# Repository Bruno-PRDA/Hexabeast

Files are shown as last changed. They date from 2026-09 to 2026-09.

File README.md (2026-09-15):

# Hexabeast

An 18-servo FPV hexapod: designed in SolidWorks, simulated in Gazebo, driven
by ROS 2, and flown from a phone over its own WiFi.

| | |
|---|---|
| Size | 34 cm foot span, 18 cm body, ~1.3 kg |
| Servos | 18x DT996 (MG996R form factor, 15 kg.cm digital) at 6 V |
| Brain | ESP32-S3 camera module, SoftAP, MJPEG video + WebSocket control |
| Drivers | 2x PCA9685, 32 PWM channels from two I2C pins |

Sizing is not arbitrary: `tools/scale_torque.py` puts the DT996 ceiling at
~41 cm foot span, and 34 cm leaves a comfortable margin. See
[docs/hardware.md](docs/hardware.md).

## The one rule

**The robot's brain never touches hardware directly.** Inverse kinematics,
gait generation and body control are pure functions of numbers in, numbers
out. Sensors and servos sit behind a thin interface with two implementations:
one that talks to real pins, one that talks to the simulator. Same control
code in both worlds - so a gait that walks in the sim walks on the robot, and
a bug found on the robot can be reproduced in the sim.

## Layout

```
ros2_ws/src/
  hexapod_description/   URDF (placeholder generated from the config; the SolidWorks
                         export replaces its body half), ros2_control config, Gazebo
                         test world, launch files
  hexapod_gait/          Python: robot_config (single source of truth), leg_ik, gait
                         (pure functions, later ported to the ESP32), gait_node (ROS 2)
firmware/              ESP32-S3: servos, calibration, gait. See firmware/README.md
tools/
  gen_urdf.py            regenerates description + controller config; --check verifies
                         the URDF joint chain against the IK, no ROS needed
  gen_firmware_header.py robot_config.py -> firmware/include/robot_geometry.h
  test_firmware.py       compiles the firmware kinematics and checks them against
                         the Python reference; needs only `pip install ziglang`
  measure_cad.py         volumes, masses and joint axes from STL/STEP exports
  render_cad.py          draws the exported STLs from four angles
  check_ik.py            IK round-trip and joint-travel report (servo centre table)
docs/
  wsl-ros2-setup.md      installing WSL2 + ROS 2 Jazzy + Gazebo Harmonic, running the sim
  solidworks-export.md   naming and axis conventions for the sw2urdf export
  hardware.md            wiring, power, camera/FPV link, servo calibration, torque
  bom.md                 electronics bill of materials with addresses and gotchas
  cad-measurements.md    the CAD leg measured, and why it exceeds the DT996 budget
sim/godot/               ARCHIVED Phase 0/1 Godot simulation. Its findings are kept below
                         and in hardware.md; it is not developed further.
```

## Running the simulation

Everything Gazebo-side runs inside WSL2 - see [docs/wsl-ros2-setup.md](docs/wsl-ros2-setup.md).
Once installed:

```
ros2 launch hexapod_description sim.launch.py
ros2 run teleop_twist_keyboard teleop_twist_keyboard
```

The gait node listens on `/cmd_vel` and drives the 18 joints through a
`JointGroupPositionController`. In Gazebo a position command becomes a joint
velocity target clamped to the URDF `velocity` limit and enforced up to its
`effort` limit - the servo's free speed and stall torque from `robot_config.py`.
The servo model comes with the physics engine.

## Roadmap

- [x] **Phase 0 - kinematic sim** (Godot, archived). Proved geometry, IK and
      gait timing; produced the servo-centre calibration table.
- [x] **Phase 1 - physics sim** (Godot, archived). Found the servo modelling
      lessons below and measured the torque demand of every manoeuvre.
- [ ] **Phase 2 - Gazebo.** WSL2 + ROS 2 Jazzy + Gazebo Harmonic. The
      placeholder description walks the same course under the same gait.
      Packages written; need WSL to build and verify.
- [ ] **Phase 3 - SolidWorks.** Model the robot, export with sw2urdf, drop the
      body half into `hexapod_description`. Real masses and inertias.
- [~] **Phase 4 - ESP32 firmware and FPV.** Servos over two PCA9685s, bench
      calibration and the gait loop are written, with the kinematics checked
      against the Python reference (2615 checks, 0 failures). Still to come:
      MJPEG stream and a WebSocket taking the same command the sim's gait node
      takes - one brain, sim and real robot. The phone opens `192.168.4.1`;
      no app. See [firmware/README.md](firmware/README.md).
- [ ] **Phase 5 - the real robot.** Calibrate per `docs/hardware.md`, stand,
      walk, then close the loop on the IMU and the foot switches.

## What the Godot physics said (Phase 1, archived)

Measured in the sim with the defaults above (1.32 kg, MG996R-class servos):

| Situation | Peak torque | Outcome |
|---|---|---|
| standing | 0.25 N.m | steady, 1 deg deflection |
| walking 0.1 m/s on the flat | 0.39 N.m | tripod pattern clean, level within 2 deg |
| turning in place at 1 rad/s | 0.78 N.m | body yaw rate 1.02 rad/s - the tightest case |
| 12 mm kerb | 0.46 N.m | crossed |
| 5 deg ramp, climbing | 0.83 N.m | climbed - the heaviest sustained load |
| hill top and 5 deg descent | 0.45 N.m | traversed, level within 2 deg |
| 7 cm drop-off (before the hill got its descent) | - | fell; stumble and fall detectors fired |

So an MG996R build has a 2.3x margin walking on the flat and almost none turning or climbing. If the
real robot weighs more than 1.3 kg, or you want it to turn briskly, plan on
20 kg.cm servos (DS3218 class, ~2 N.m).

Three lessons that carry over to any simulator: servo damping is not a free
parameter (it is T_stall / w_free, the speed-torque line); a geared servo's
output shaft carries reflected rotor inertia far above the link's own; and a
servo must be allowed to stall - Gazebo enforces the URDF `effort` limit
natively, Godot needed it emulated.

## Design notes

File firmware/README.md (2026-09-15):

# Hexabeast firmware

ESP32-S3. Stage 1: servos, calibration and the gait loop — everything testable
on a bench with a board, two PCA9685s and as few as one servo. WiFi, the camera
and the FPV link come next.

## Layout

```
include/
  robot_geometry.h   GENERATED from robot_config.py - never edit
  leg_ik.h           inverse kinematics, pure, no Arduino
  gait.h             tripod gait, pure, no Arduino
  servo_bus.h        two PCA9685s over I2C
src/
  main.cpp           serial console, calibration, gait loop
  servo_bus.cpp
test/
  test_kinematics.cpp  C++ checked against the Python reference
  fixtures.h           GENERATED expected values
```

`leg_ik.h` and `gait.h` carry no Arduino dependency on purpose: that is what
lets them compile and be tested on a laptop, and it is why the same maths can
be trusted in the simulator and on the robot.

## The geometry is generated, not typed

`robot_config.py` owns the robot's dimensions. The firmware gets its copy from
the generator, so the two cannot drift:

```bash
python tools/gen_firmware_header.py           # write robot_geometry.h
python tools/gen_firmware_header.py --check   # fail if it is stale
```

Re-run it after any geometry change, the same as `gen_urdf.py`.

## Testing without hardware

```bash
python tools/test_firmware.py
```

This regenerates the fixtures **from the Python**, compiles the C++ against
them and runs it — so "the firmware agrees with the simulator" is a checked
fact. It uses zig's C++ frontend (`pip install ziglang`), which needs no admin
rights and no Visual Studio.

Current state: 2615 checks, 0 failures. Worst walking excursion 33.7 deg of the
80 available.

## Building and flashing

Needs [PlatformIO](https://platformio.org/install/cli) (`pip install platformio`).

```bash
cd firmware
pio run                 # build
pio run -t upload       # flash
pio device monitor      # serial console at 115200
```

## Bench calibration

Do this **before the legs are attached to anything**. Horns fitted at the wrong
angle will drive a leg into its own chassis on the first step.

1. **Power the PCA9685s from their UBECs**, not from the ESP32. Common ground.
   Boards must answer at `0x40` and `0x41` — if one is missing, the A0 jumper on
   board 1 is unbridged, or the INA219 is still squatting on `0x40`.

2. Flash, open the monitor. It boots **relaxed**: every output dark, servos
   limp. `x` is the panic key at any time.

3. `e` to enable, then `k` for calibration mode. All 18 servos go to their
   mechanical centre.

4. **Fit each horn now**, with the leg held at its design angle:

   | Joint | Joint angle at servo centre |
   |-------|-----------------------------|
   | coxa | 0 deg — leg straight out along its rest direction |
   | femur | +45 deg — femur raised |
   | tibia | -105 deg — tibia folded down |

   These come from `JOINT_CENTER_DEG` and change whenever the geometry does.
   Re-run `python tools/check_ik.py` if in doubt; it prints them.

5. **Trim.** `j<n>` selects a joint (`n`/`p` step through them). `+`/`-` move
   the trim 10 us, `>`/`<` by 2. A servo spline is about 1.4 deg per tooth, so
   trim covers what the horn cannot.

6. **Direction.** Press `f` and watch the joint. If it moves the wrong way for
   a positive angle, leave it flipped. The defaults in `SERVO_DIR` are the
   mirror assumption — left legs inverted — and are a guess until you check.

7. `s` saves trim and direction to NVS. They survive reflashing.

## Running the gait

`r` for run mode, then `w<vx>,<vy>,<wz>`:

```
w0.08,0,0     forward at 80 mm/s
w0,0,0.5      turn left
h             halt
x             relax
```

Commands expire after 500 ms. A console that goes quiet stops the robot — the
same guarantee the WiFi link will need, which is why it lives in the control
loop rather than in the transport.

On enable, the legs ease from centre to stance over 2 seconds rather than
snapping, and the gait phase only advances while a command is non-zero, so
stopping settles the feet at neutral instead of freezing mid-swing.

## Wiring

Pins in `main.cpp`. I2C defaults to GPIO 1 (SDA) and 2 (SCL) — any free pair
works on the S3, but avoid 19/20, which are USB D-/D+.

Full parts list and the I2C address map: [../docs/bom.md](../docs/bom.md).

## Not done yet

- WiFi SoftAP, WebSocket control, MJPEG stream, the phone page
- IMU (MPU6050) and foot switches (PCF8574)
- Battery telemetry (INA219)
- Body attitude control — using the IMU to keep the chassis level on a slope

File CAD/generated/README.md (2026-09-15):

# Generated leg parts

Produced by `python tools/gen_leg_cad.py` from `robot_config.py`. Do not edit
by hand — regenerate.

| Part | Spans | Printed (30 % infill) |
|---|---|---|
| `coxa_link` | coxa axis -> femur servo axis, 25 mm | ~5.3 g |
| `femur_link` | femur axis -> knee servo axis, 59 mm | ~6.5 g |
| `tibia` | knee axis -> foot tip, 109 mm | ~8.6 g |
| `body` | six coxa mounts, electronics, battery, mast socket | ~69 g |
| `abdomen` | dome over the rear, houses the UBECs | ~12 g |
| `head` | LCD face, proximity sensor and camera, tilted 15 deg down | ~21 g |
| `assembly.stl` | the lot at stance pose - for viewing, not printing | - |

Print six each of the three leg parts, one body, one dome, one head: **224 g**
of plastic. With 18 servos and the battery that is **1.53 kg** all-up.

## Open: the camera board does not fit the turret

`gen_robot_cad.py --check` warns about this on every run, deliberately. A
Freenove ESP32-S3-WROOM CAM is **57.1 x 28.1 mm**; the turret it is drawn on is
30 x 24. It was modelled 45 x 27 x 20, which is why nothing complained before.
Three ways out, none of them free:

- **Grow the turret** to about 62 x 34. Simplest, but it puts a panel bigger
  than the face on top of a 72 mm neck - the worst possible place for mass on
  a walking robot.
- **Board under the plate, camera on a flex extension.** The belly has room at
  x 20..70. The camera is a parallel DVP bus at 20 MHz, so a long flex is a
  real signal-integrity risk.
- **Swap to a XIAO ESP32S3 Sense** (21 x 17.5 mm, camera onboard), which fits
  the turret as drawn. A BOM change.

`.step` imports into SolidWorks as a solid body — editable geometry, but no
feature tree. `.stl` goes straight to the slicer.

Axis spacing is verified from the exported STLs, not just asserted by the
script: 25.02 / 58.97 / 109.01 mm against the 25 / 59 / 109 in the config.

**The servo tab holes are slots, and that is not a nicety.** MG996R clones put
the long pitch anywhere between 47.8 and 49.5 mm. The original 4.3 mm round
hole on a 49.5 nominal only reached down to 48.85, so a servo from the bottom
of that spread would simply not have bolted on. They are now 5.1 x 3.4 mm slots
on a 48.65 nominal, M3, which covers the whole range - a caliper check is a
sanity check rather than a gate.

## Two things the assembly check found

**The head height is set by the knees, not the body.** A front leg's
knee rises to 80 mm above the plate at the top of its swing. The first draft
put the camera at 62 mm, which would have had legs sweeping through the shot
every stride. The camera sits at 115 mm, clearing the worst case by 35 mm; the LCD face is
at 86 mm and the proximity sensor at 60 mm.

**Styling is packaging, not decoration.** The plate is a faceted profile down
the centreline, drawn out to a point at each hip and lightened with triangular
voids; the tibia and femur are Warren trusses between two edge rails. Every
station of the profile is set by what sits under it - the tail by where the
dome's wall ring lands, the waist by the servo driver mounted across it, the
thorax by the hip spacing - so the outline follows the packaging rather than
being drawn over it.

The voids are not placed by eye. A triangular lattice proposes candidates and
each has to earn its place: miss every hole, cutout and bearing face by 4 mm,
and lie wholly inside the outline eroded by 6.5 mm. The lattice's own phase is
swept, which matters more than it sounds like it should - across the 16 offsets
tried, the number that fits runs from 0 to 10 per half-plate. 20 voids survive,
taking 22 cm2 out of the plate, and adding a component later just makes some of
them vanish.

**A hole that doesn't cut looks exactly like a hole that does.** build123d
extrudes a face along its own normal, so a clockwise polygon builds its prism
*below* the plane - subtract it and nothing is removed. Half the truss bays
alternate winding by construction and every mirrored void flips it again, so
most of them were quietly doing nothing and the parts still rendered perfectly.
Winding is now normalised in one place, and both generators probe for material
where each void should be.

**A hole is a subtraction, so the check could not see a single screw.** The
interference check compared solids, and holes carry no fastener - so the shunt
and the I2C expander both sat directly under fastener tails with about 1.5 mm
of air, and nothing flagged it. Screws, nuts and proud heads are now modelled
as solids from the same hole list the plate is drilled from. The sliver
threshold came down from 60 mm3 to 5 mm3 at the same time: 60 was not small
enough to be safe, and was hiding a 40 mm3 overlap where the OLED and the ToF
occupied the same space.

**Things on the head were placed in the body's frame, not the face's.** The
face tilts 15 degrees nose-down; 22 mm below its centre that swings it 5.7 mm
backwards. The boards were positioned at a fixed offset as though the head
stood upright, which put the proximity sensor 0.9 mm inside the slab it bolts
behind. Everything on the face now goes through `head_frame()`, the same chain
`make_head()` builds the face on.

**Each foot lands 11.9 mm off the ideal.** The femur servo bolts to a wall, so
its shaft cannot sit on the leg's centre plane - the offset is the servo's half
width plus clearance plus half the wall. Seen from the coxa axis it is a
rotation, not a reach error: the stance hexagon is turned 6.65 deg, and the true
radius is 102.69 mm against a nominal 102. Trim each coxa by -6.65 deg and the
feet return to the model's radial line, leaving 0.7 mm of reach error - under
1 %, so torque and gait are untouched.

All six legs are offset the same rotational sense, which keeps the stance
rotationally symmetric and balanced. The payoff is that all six legs are the
**same printed part**, not mirrored pairs.

Print flat on the bed, no supports needed. Three perimeters minimum — the
walls are 3 mm, and with the middle of each link trussed out it is the rails
that carry the bending load.

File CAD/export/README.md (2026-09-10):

# CAD exports

Drop STEP and STL exports here, then run:

    python tools/measure_cad.py

STL gives exact volumes (hence real part masses); STEP keeps the analytic
cylinders, so the tool can find each servo shaft's true axis and measure the
axis-to-axis link lengths that `robot_config.py` needs.

Regenerate these whenever the parts change - they are derived from the
`.SLDPRT` files one directory up, which remain the source of truth.

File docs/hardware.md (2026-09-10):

# Hardware

## Servo drivers: two PCA9685 boards

Shopping list with part numbers, quantities and prices: [bom.md](bom.md).

18 servos, 16 channels per board. Two boards on the same I2C bus:

| Board | I2C address | Solder jumper | Drives |
|---|---|---|---|
| 0 | `0x40` | none | left legs FL, ML, RL (channels 0-8) |
| 1 | `0x41` | bridge **A0** | right legs FR, MR, RR (channels 0-8) |

Bridge A0 on the second board only, or both answer at `0x40` and neither
works. The channel map per joint is in `sim/godot/scripts/robot_config.gd`;
channels 16-31 in that file are board 1's 0-15.

ESP32 default I2C pins: **SDA = GPIO 21, SCL = GPIO 22.** Both boards' SDA,
SCL, GND and VCC (3.3 V logic) daisy-chain.

## Power - the part that breaks robots

**Never power servos from the ESP32's 5 V pin.** It cannot source the current
and the resulting brownout resets the ESP32 mid-step.

Each board has a separate V+ terminal block for servo power. Budget:

| Servo | Stall current | Realistic walking draw (18 servos) |
|---|---|---|
| SG90 / MG90S | ~0.7 A | 3-5 A peaks |
| MG996R | ~2.5 A | 8-12 A peaks |
| DS3218 / 20 kg class | ~3 A | 10-15 A peaks |

Feed V+ from a supply rated for the peak, e.g. a 2S LiPo (7.4 V) through a
**5 V / 10 A+ UBEC** for 5 V servos, or direct 6-7.4 V for servos rated for it.
Put a 1000 uF+ electrolytic across V+/GND on each board to absorb the
current spikes when all six legs move at once. Common the ESP32 ground with
the servo ground.

## Camera and FPV control

### Board: an ESP32-S3 camera module, not the old ESP32-CAM

A camera's parallel (DVP) interface eats about 16 GPIO. On the AI-Thinker
ESP32-CAM that leaves roughly four usable pins, no native USB (you need an
FTDI adapter to flash), 4 MB PSRAM, and a well-earned reputation for
browning out. An **ESP32-S3 camera board** (Freenove ESP32-S3-WROOM CAM,
XIAO ESP32S3 Sense, or similar) gives 8 MB PSRAM, hardware JPEG, native USB
flashing, better WiFi throughput and more free pins for the same money.

Either way the servos do **not** hang off the ESP32's GPIO - that is what the
two PCA9685 boards are for, and with a camera fitted they stop being a
convenience and become the only option:

- 18 legs (24 with the arm) from **two pins**, SDA and SCL.
- The PCA9685 generates the 50 Hz servo pulses **in hardware**. Servo timing
  is then immune to whatever the CPU is doing. Bit-banging PWM from a board
  that is simultaneously encoding JPEG and servicing WiFi produces visible
  twitching; this design cannot suffer from it.

### Topology: the robot is its own access point

Run the ESP32 in **SoftAP** mode - it publishes a WiFi network (say
`HEXABEAST`), the phone joins it, and the robot lives at `192.168.4.1`. No
router, so it works in a park as well as on the bench, and latency is one hop.
Station mode (joining your home WiFi) only makes sense if you want the phone
to keep internet access at the same time; range then belongs to the router.

Fit a board with a **u.FL external antenna** connector if range matters: the
onboard PCB antenna manages 15-25 m, an external whip 50 m or more.

### The link: video one way, intent the other

| Channel | Transport | Rate |
|---|---|---|
| Video | MJPEG over HTTP, `multipart/x-mixed-replace` on `/stream` | QVGA 320x240 at ~25 fps, VGA 640x480 at ~12-15 fps |
| Control | WebSocket on `/ws`, JSON or packed binary | 20 Hz is ample |

Expect 150-300 ms of glass-to-glass latency. Fine for driving, not for
reflexes.

**The phone needs no app.** The ESP32 serves one HTML page: an `<img>` pointed
at `/stream` with two touch joysticks overlaid, which post to the WebSocket.
Open a browser at `192.168.4.1` and that is the FPV rig, on iOS and Android
alike.

### What crosses the link is intent, never joint angles

The control message carries what the *body* should do - forward, sideways,
turn - and the gait runs **on the ESP32**:

```json
{"vx": 0.08, "vy": 0.0, "wz": 0.4, "gait": "tripod"}
```

That is deliberately the same shape as the `/cmd_vel` Twist the simulation's
gait node already consumes, so the phone drives the sim and the real robot
identically. It also means a WiFi dropout makes the robot *stop*, not
collapse mid-step: the last command expires, velocity goes to zero, the legs
settle. Streaming 18 joint angles over WiFi at 50 Hz would put a lossy radio
link inside the control loop - never do that.

### Power, again - the camera makes it worse

The camera and WiFi transmitter together want a clean 500 mA-1 A, and they
are far more brownout-sensitive than the ESP32 alone. Servo current spikes
that a bare ESP32 shrugged off will drop the video feed or reset the board.

Give logic and servos **separate regulators** off the same battery:

```
2S LiPo 7.4 V --+-- 6 V / 10 A UBEC ---- PCA9685 V+  (servos)
                |
                +-- 5 V / 2 A BEC ------ ESP32-S3 5 V (logic + camera)

grounds common at one point; 1000 uF on the servo rail, 470 uF at the ESP32
```

### Mounting

The body pitches and rolls with every gait cycle, so the steadiest place for
the camera is the **body front**, as low and as close to the centre of
rotation as the frame allows. Two spare PCA9685 channels make a pan/tilt head
worth having - it lets you look around without turning the whole robot, which
costs the most torque of any manoeuvre (see below).

## Servo torque and how big the robot can be

The Phase-1 physics sim measured the peak torque any one servo must supply,
for the current geometry (foot span ~34 cm) at 1.3-1.6 kg all-up:

| standing | walking 0.1 m/s | 12 mm kerb | turning 1 rad/s | climbing 5 deg |
|---|---|---|---|---|
| 0.25 N.m | 0.39 N.m | 0.46 N.m | 0.78 N.m | 0.83 N.m |

Turning in place and climbing are the stress cases; flat walking is trivial.

### What a DT996 can carry

The DT996 is an MG996R-form-factor digital servo advertised at 15 kg.cm
(1.49 N.m at 6 V). Designing to 75 % of that - 1.10 N.m, the value in
`robot_config.py` - covers stall spikes, gear wear and the gap between a
clone's label and its real output.

`tools/scale_torque.py` extrapolates the measured 0.83 N.m datapoint across
robot sizes. The physics that matters: **the 18 servos are a fixed 1 kg no
matter how big the frame is**, so mass barely grows with size while the leg's
lever arm grows linearly. Torque tracks mass x reach.

| foot span | body | all-up | climb torque | verdict on DT996 |
|---|---|---|---|---|
| 24 cm | 13 cm | 1.4 kg | 0.52 N.m | comfortable even at 4.8 V |
| 29 cm | 15 cm | 1.4 kg | 0.66 N.m | comfortable even at 4.8 V |
| **34 cm** | **18 cm** | **1.5 kg** | **0.83 N.m** | **comfortable - the current design** |
| 39 cm | 21 cm | 1.7 kg | 1.04 N.m | OK at 6 V, tight on obstacles |
| 44 cm | 23 cm | 1.8 kg | 1.29 N.m | walks flat, stalls climbing |
| 51 cm+ | 27 cm+ | 2.1 kg+ | 1.73 N.m+ | too big for DT996 |

**Ceiling: ~41 cm foot span** with a 25 % margin, ~37 cm with the arm fitted.
Past that you need 20-25 kg.cm servos (DS3218 class, ~2 N.m) and a supply to
match. Note how fast it runs out - going from 34 to 51 cm doubles the torque
demand for only 40 % more size, because reach and mass grow together.

### The arm costs 4 cm of that budget (currently off)

`ARM = False` in `robot_config.py`, so the build is a plain hexapod: 18
servos, 1.32 kg, 73 mm of static margin. Recorded here for when it comes back.

Six more servos (0.33 kg) hung off the front cut the comfortable span from 41
to 37 cm, shift the centre of mass 23 mm forward (margin 73 -> 52 mm, still
stable), and the shoulder servo limits the gripper to roughly **275 g at 24 cm
full reach** - fold the arm in to lift more. Flipping `ARM` back on regenerates
the URDF, the controller list and the launch file's spawner together.

Re-run `python tools/scale_torque.py --arm` after changing any mass or length.

## Sensors

| Sensor | Bus / pins | Notes |
|---|---|---|
| IMU (MPU6050 `0x68` / BNO055 `0x28`) | shared I2C | BNO055 does sensor fusion on-chip and hands back a clean orientation; MPU6050 needs a complementary filter in firmware. Mount rigidly at body centre. |
| Foot contact switches x6 | one GPIO each, `INPUT_PULLUP` | Micro-switch or a spring-loaded foot tip. Wire to GND so a press reads LOW. Debounce in software. |

Safe GPIOs for the switches: 13, 14, 25, 26, 27, 32, 33. Avoid 0, 2, 12, 15
(boot-mode strapping pins) and 34-39 (input-only, no pull-ups).

## Servo calibration - do this before the first stand

A joint angle is not a servo angle. The IK found that the tibia lives around
-94 deg for the whole gait, so a horn fitted with the servo centred and the leg
straight would spend its life jammed at an end stop. Fit each horn with the
leg held in the **centre pose**:

| Joint | Hold the leg at | Servo centre = |
|---|---|---|
| Coxa | pointing straight along its rest direction | 0 deg |
| Femur | raised 22 deg above horizontal | +22 deg |
| Tibia | folded 94 deg below the femur line | -94 deg |

Procedure per servo:

1. Command 1500 us (centre) with the horn **off**.
2. Hold the leg segment at the angle in the table.
3. Press the horn on the nearest spline tooth, screw it down.
4. Record the residual error - the spline is coarse (~15 deg on a 25 T) so you
   will not land exactly. That residual goes in a per-servo trim table in
   firmware.

The centre values come from `tools/check_ik.py`; re-run it after changing
any link length in `robot_config.gd` and update this table.

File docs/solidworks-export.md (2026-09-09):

# Du modèle SolidWorks à Gazebo

La simulation lit une description URDF. L'exporteur gratuit **SolidWorks to
URDF** (sw2urdf, `github.com/ros/solidworks_urdf_exporter`) la produit
depuis l'assemblage : repères, axes, masses, inerties, limites, maillages.
Ce qu'il sort remplace `urdf/hexapod_body.urdf.xacro` ; le reste de la chaîne
(contrôleurs, capteurs, Gazebo) ne bouge pas **si les noms sont respectés**.

## Ce qui doit sortir de SolidWorks

| Élément | Convention attendue |
|---|---|
| Corps | lien `base_link`, repère au centre du corps, **X vers l'avant, Y vers la gauche, Z vers le haut** |
| Liens de patte | `FL_coxa_link`, `FL_femur_link`, `FL_tibia_link` — idem pour `ML`, `RL`, `FR`, `MR`, `RR` (F/M/R = avant/milieu/arrière, L/R = gauche/droite) |
| Articulations | `FL_coxa`, `FL_femur`, `FL_tibia`, … ; type *revolute* |
| Axe de la hanche (coxa) | Z du repère de l'articulation, positif = la patte tourne vers la gauche de sa direction de repos |
| Axes fémur et tibia | **−Y** du repère de l'articulation, positif = le segment se lève |
| Zéro des articulations | patte tendue : coxa dans sa direction de repos, fémur dans l'axe de la coxa, tibia dans l'axe du fémur |
| Repère de chaque articulation | origine sur l'**axe de rotation du servo** (pas au centre de la pièce), X pointant vers l'articulation suivante |
| Unités | mètres et kilogrammes — sw2urdf convertit depuis les mm, vérifier `<mass>` et les `<origin>` à l'export |

Les six directions de repos actuelles (angle depuis +X) : FL 45°, ML 90°,
RL 135°, FR −45°, MR −90°, RR −135°. Elles ne sont pas imposées : si le châssis
place les hanches ailleurs, on met à jour `LEGS` dans `robot_config.py` et
`tools/gen_urdf.py --check` valide que la démarche est toujours atteignable.

## Dans sw2urdf, concrètement

1. Créer dans l'assemblage un **point** et un **axe** de référence par
   articulation, sur l'axe de sortie du servo. L'exporteur s'en sert pour
   placer l'origine et l'axe du joint.
2. Regrouper les pièces en 19 liens : le corps (avec servos de hanche,
   électronique, batterie) et 3 liens par patte. Un servo appartient au lien
   qui le porte, pas à celui qu'il entraîne.
3. Affecter les matériaux (PLA, aluminium, masse des servos en pièces
   « pleines » avec densité ajustée) : ce sont eux qui donnent masses et
   inerties, et le verdict sur le couple en dépend directement.
4. Exporter. sw2urdf produit un paquet avec `urdf/` et `meshes/` (STL).

## Brancher l'export

1. Copier le contenu de `<robot>` du fichier exporté dans
   `ros2_ws/src/hexapod_description/urdf/hexapod_body.urdf.xacro`, et les
   maillages dans `hexapod_description/meshes/` (ajouter `meshes` à
   `install(DIRECTORY …)` dans `CMakeLists.txt`). Les chemins de maillage
   deviennent `package://hexapod_description/meshes/….STL`.
2. Garder des **collisions simples** : boîte pour le corps, cylindre pour le
   tibia et une sphère au bout du pied, comme dans le fichier généré. Un
   maillage détaillé en collision rend la physique lente et instable sans rien
   apporter. La sphère du pied doit rester la première collision du tibia :
   c'est elle que le capteur de contact référence.
3. Reporter dans `robot_config.py` ce que la CAO a fixé : longueurs d'axe à
   axe, positions des hanches, masses. Lancer `python tools/gen_urdf.py --check`
   pour régénérer contrôleurs et pont, et vérifier la cinématique.
4. `ros2 launch hexapod_description display.launch.py` : bouger chaque
   curseur, vérifier que fémur et tibia se **lèvent** pour un angle positif et
   que la coxa tourne vers la gauche. Si un axe est inversé, corriger le signe
   de `<axis>` plutôt que le code.

## Ce que SolidWorks ne remplace pas

SolidWorks Motion sait faire de la cinématique, pas la boucle de commande des
servos ni la démarche : c'est le rôle de Gazebo et du nœud `hexapod_gait`.
Les deux sont complémentaires — SolidWorks dit *ce qu'est* le robot, Gazebo
dit *ce qu'il fait*.

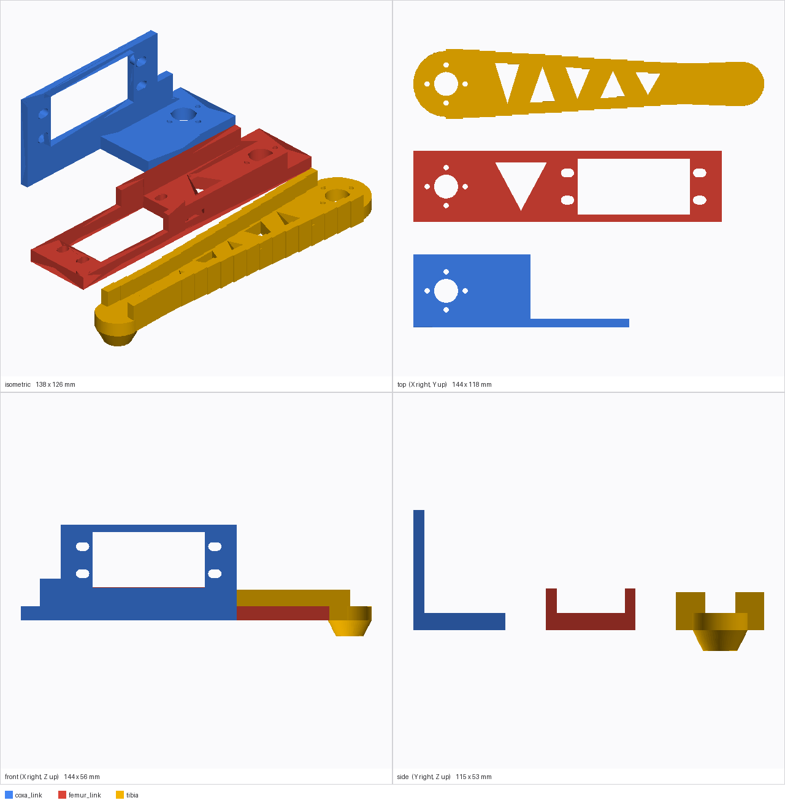
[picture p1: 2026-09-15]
docs/cad-leg-views.png

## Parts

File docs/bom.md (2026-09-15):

# Electronics bill of materials

For the locked spec: 18-servo hexapod, 34 cm foot span, ~1.3 kg, DT996 servos
at 6 V, ESP32-S3 camera, FPV over its own WiFi. Prices are rough EUR for
France, ex-servos, and drift constantly - treat them as budgeting, not quotes.

## The whole robot hangs off one I2C bus

A camera's parallel interface consumes about 16 GPIO, which leaves nowhere
near enough pins for 18 servos plus sensors. It doesn't matter, because
everything here is I2C - two pins, five devices:

| Device | Address | Function | Notes |
|---|---|---|---|
| PCA9685 #0 | `0x40` | left legs FL/ML/RL, 9 channels | address jumpers untouched |
| PCA9685 #1 | `0x41` | right legs FR/MR/RR, 9 channels | **bridge A0** |
| MPU6050 | `0x68` | 6-axis IMU | `AD0` low |
| PCF8574 | `0x20` | 6 foot contact switches | inputs, switch to GND |
| INA219 | `0x44` | battery voltage + current | **must be moved off `0x40`** - see gotchas |
| SSD1306 | `0x3C` | 1.3" OLED - the robot's face | `0x3D` if its jumper is bridged |
| VL53L0X | `0x29` | time-of-flight proximity | fixed at boot; software-settable |

Run the bus at 400 kHz. `0x70` is the PCA9685 "all call" address and `0x00`
its reset address, so avoid both if you add anything later.

## 1. Actuation

| # | Part | Qty | ~EUR | Why |
|---|---|-----|---|-----|
| 1.1 | DT996 digital servo, 15 kg.cm, 180 deg | **20** | 90-120 | 18 joints + 2 spares. These strip gears, and a dead servo with two weeks of shipping ahead of it stops the build |
| 1.2 | Servo extension lead, 3-pin, 200-300 mm | 12 | 10 | The femur and tibia servos sit out on the legs; only the six coxa servos are close enough to reach the body on their stock leads |
| 1.3 | Servo horn / bracket set | 1 kit | 15 | Usually bundled with the servos - check before ordering |

## 2. Servo drive

| # | Part | Qty | ~EUR | Why |
|---|---|-----|---|-----|
| 2.1 | PCA9685 16-channel 12-bit PWM driver | 2 | 12-18 | 32 channels from two pins. Generates the 50 Hz pulses **in hardware**, so servo timing is immune to whatever the CPU is doing while encoding JPEG |

Nine servos per board. Splitting left and right legs across the two also
splits the current, which matters (see the power budget).

## 3. Compute and camera

| # | Part | Qty | ~EUR | Why |
|---|---|-----|---|-----|
| 3.1 | **Freenove ESP32-S3-WROOM CAM** (OV2640, 8 MB PSRAM, USB-C) | 1 | 15-20 | 8 MB PSRAM, hardware JPEG, native USB so no FTDI adapter, good broken-out GPIO. XIAO ESP32S3 Sense is a smaller alternative but exposes very few pins |
| 3.2 | u.FL / IPEX 2.4 GHz antenna + pigtail | 1 | 5 | Only if your board has the connector. Onboard PCB antenna gives 15-25 m; an external whip 50 m+ |
| 3.3 | microSD card, 16-32 GB, class 10 | 1 | 8 | Optional - onboard recording and log capture |

Assign I2C to any two free GPIO in firmware; the S3's GPIO matrix is flexible.
**Avoid GPIO 19 and 20** - they are USB D-/D+ and you want native USB flashing.

## 4. Power - the part that breaks robots

| # | Part | Qty | ~EUR | Why |
|---|---|-----|---|-----|
| 4.1 | LiPo 2S 7.4 V, **2200 mAh**, 25C+, XT60 | 1 | 15-22 | Sized by the robot, not the runtime: a 2200 pack is ~90 x 34 x 20 mm and slings under the plate between the rear coxa servos, which leave only ~8 mm either side. A 5000 pack is 132 x 43 and will not pass. Vendor spread is large - 1500 mAh packs alone range 69-107 mm long - so measure yours before cutting straps |
| 4.2 | UBEC / switching BEC, **6 V 10 A** | 2 | 16-24 | One per PCA9685. Do **not** feed 7.4 V to these servos - they are 6 V parts |
| 4.3 | Buck converter, 5 V 3 A (MP1584 or similar) | 1 | 5 | Separate logic rail for the ESP32 and camera |
| 4.4 | Electrolytic capacitor, 1000-2200 uF, 16 V | 2 | 3 | One across V+/GND at each PCA9685 |
| 4.5 | Electrolytic capacitor, 470 uF, 10 V | 1 | 1 | At the ESP32's 5 V input |
| 4.6 | XT60 connector pair | 2 | 4 | Battery and a spare |
| 4.7 | Inline blade fuse holder + 20 A fuses | 1 | 5 | A shorted servo lead on an unfused LiPo starts a fire |
| 4.8 | Rocker/toggle switch rated 20 A+, or XT60 anti-spark | 1 | 6 | Small switches weld shut at these currents |
| 4.9 | LiPo low-voltage alarm buzzer | 1 | 5 | 2S LiPo below ~3.3 V/cell is permanently damaged. The robot will happily walk until it kills the pack |
| 4.10 | Balance charger (IMAX B6 or similar) + LiPo safe bag | 1 | 30-40 | Skip only if you already charge LiPos |

### Budget

| Load | Draw |
|---|---|
| 18 servos, standing | ~1.5 A |
| 18 servos, walking | 3-5 A average |
| 18 servos, worst-case simultaneous move | 10-12 A peak |
| One DT996 stalled | ~2.5 A |
| ESP32-S3 + camera + WiFi | 0.4-0.8 A, spiky on TX |

Two 6 V/10 A UBECs cover the servo peak with margin and halve what each
PCA9685's traces carry. The logic rail stays separate so a servo spike cannot
brown out the camera.

```
LiPo 2S ---[20 A fuse]---[switch]---+--- 6 V 10 A UBEC --- PCA9685 #0 V+   (left legs)
                                    +--- 6 V 10 A UBEC --- PCA9685 #1 V+   (right legs)
                                    +--- 5 V 3 A buck ---- ESP32-S3 5 V    (logic + camera)

All grounds meet at ONE point. 1000 uF+ at each PCA9685, 470 uF at the ESP32.
```

## 5. Sensors

| # | Part | Qty | ~EUR | Why |
|---|---|-----|---|-----|
| 5.1 | MPU6050 6-axis IMU breakout | 1 | 3 | Body attitude. The sim models exactly this part, noise included. Upgrade: BNO055 (~25 EUR) fuses orientation on-chip and saves ESP32 cycles |
| 5.2 | PCF8574 I2C 8-bit GPIO expander | 1 | 3 | Six foot switches on a board with no spare pins. Inputs have weak pull-ups, so wire each switch to GND |
| 5.3 | Micro lever switch (SS-5GL / D2F class) | 8 | 5 | One per foot + spares. Binary contact, which is what the gait's stumble detector expects |
| 5.4 | INA219 current/voltage sensor | 1 | 5 | Battery telemetry on the FPV overlay. Knowing your remaining flight time matters more than it sounds |
| 5.5 | 1.3" OLED, SSD1306, I2C | 1 | 6 | The face. 128x64 is enough for eyes with real expression, and it draws about 20 mA |
| 5.6 | VL53L0X time-of-flight module | 1 | 5 | Proximity, 30-1200 mm. Unlike an HC-SR04 it is I2C, tiny, and unbothered by soft or angled surfaces |

## 6. Wiring and assembly

| # | Part | Qty | ~EUR | Why |
|---|---|-----|---|-----|
| 6.1 | Silicone wire 14 AWG, red/black, 2 m | 1 | 8 | Battery to fuse to switch to UBECs. 14 AWG for 20 A |
| 6.2 | Silicone wire 20-22 AWG, assorted, 10 m | 1 | 8 | Servo branches and distribution |
| 6.3 | Dupont jumper wires, F-F, 20 cm | 1 pack | 4 | I2C and sensor runs |
| 6.4 | JST-XH / screw terminal assortment | 1 | 6 | Serviceable joints - you will take this apart |
| 6.5 | Heat shrink assortment | 1 | 5 | |
| 6.6 | Small perfboard or distribution PCB | 1 | 5 | Ground star point and I2C fan-out |
| 6.7 | Cable sleeving / spiral wrap, 3 m | 1 | 5 | 18 servo leads through six moving legs. Do this or they snag |
| 6.8 | M2/M3 screw + standoff assortment | 1 | 10 | Board mounting |

## 7. Optional, and worth it

| # | Part | Qty | ~EUR | Why |
|---|---|-----|---|-----|
| 7.1 | SG90 micro servo + pan/tilt bracket | 2 | 8 | Camera pan/tilt on two spare PCA9685 channels. Looking around without turning the body avoids the most torque-expensive move the robot makes |
| 7.2 | Passive buzzer | 1 | 2 | Boot, WiFi-up, low-battery tones. Debugging a headless robot without sound is miserable |
| 7.3 | WS2812 LED strip, short | 1 | 5 | Status at a glance; doubles as headlights for the camera |
| 7.4 | USB-C cable, data-capable | 1 | 5 | Many bundled cables are charge-only |

## Gotchas that cost a build

**INA219 defaults to `0x40` - the same address as PCA9685 #0.** Bridge its
`A0` solder jumper to move it to `0x44` before wiring, or neither device works
and the fault looks like a dead bus.

**Bridge `A0` on the second PCA9685 only.** Untouched, both boards answer at
`0x40` and the right legs mirror the left ones.

**Never power servos through the ESP32's 5 V pin.** It cannot source the
current; the brownout resets the board mid-step.

**Watch the PCA9685's V+ traces.** They handle roughly 10 A total, which nine
DT996s can approach on a simultaneous move. Splitting the legs across two
boards with a UBEC each keeps you inside it. If you still see brownouts, feed
the servos from a separate distribution bus and take only the signal pin from
the PCA9685.

**Redundant I2C pull-ups.** Seven breakouts each carrying 10 k pull-ups put
about 1.4 k on the bus. That still works at 400 kHz, but if the bus is flaky,
desolder the pull-ups on all but one board.

**Servos are 6 V parts.** 2S LiPo is 8.4 V fully charged. Straight through,
that cooks them.

## Rough total

| | EUR |
|---|-----|
| Servos (20) | 90-120 |
| Everything else | 150-190 |
| Charger and LiPo safety, if new to LiPo | +35 |
| **Total** | **~240-345** |

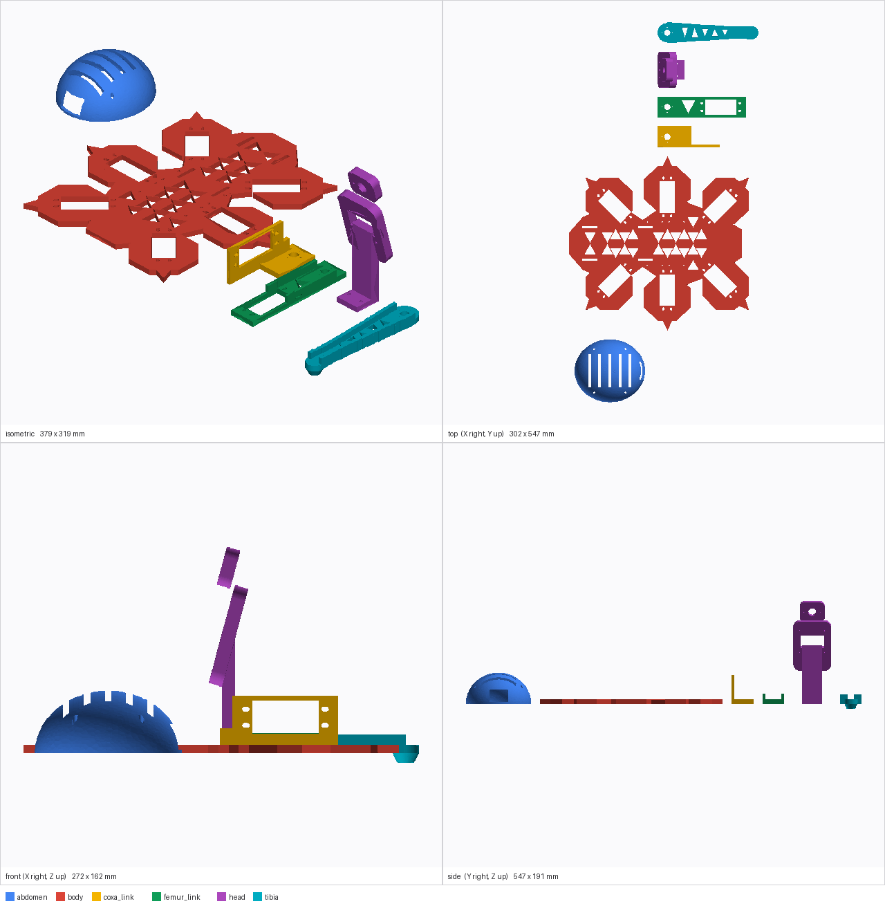
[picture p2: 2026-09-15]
docs/cad-generated-parts.png

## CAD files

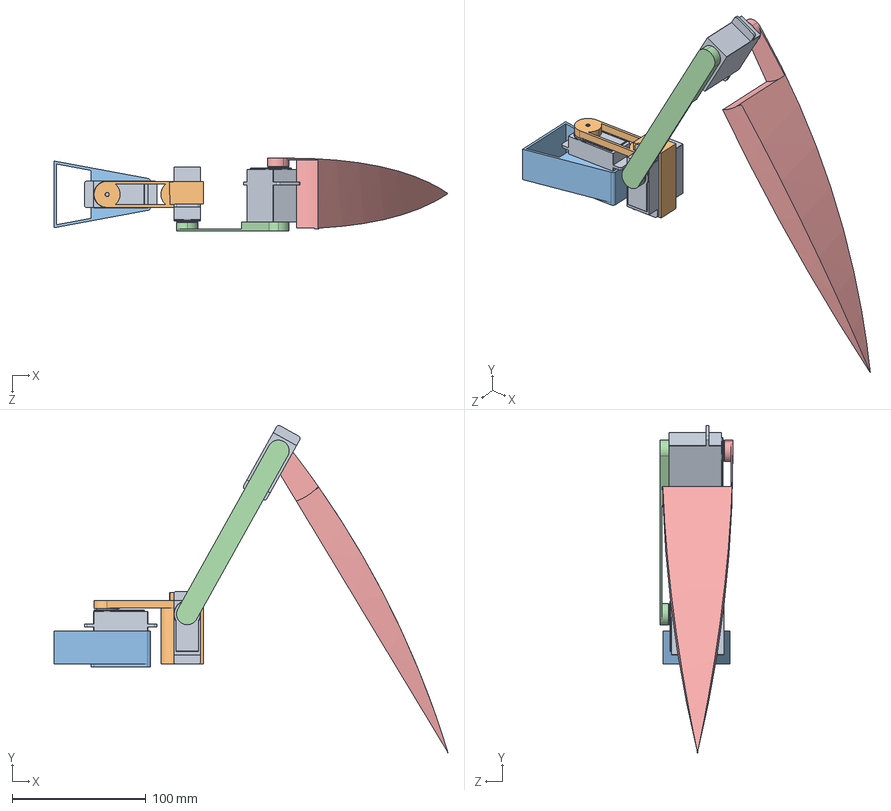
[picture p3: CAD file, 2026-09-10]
CAD/export/Assemblage1.STEP
294.9 x 245.0 x 54.5 mm
SERVO x 3
articulation 1
base
articulation 2
Pièce6^Assemblage1

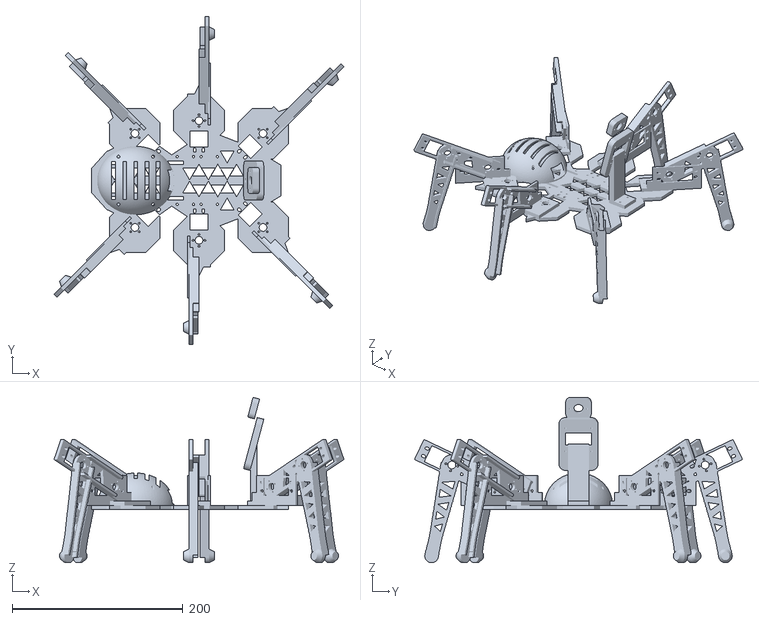
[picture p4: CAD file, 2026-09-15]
CAD/generated/assembly_printed_only.stl
339.4 x 384.1 x 193.6

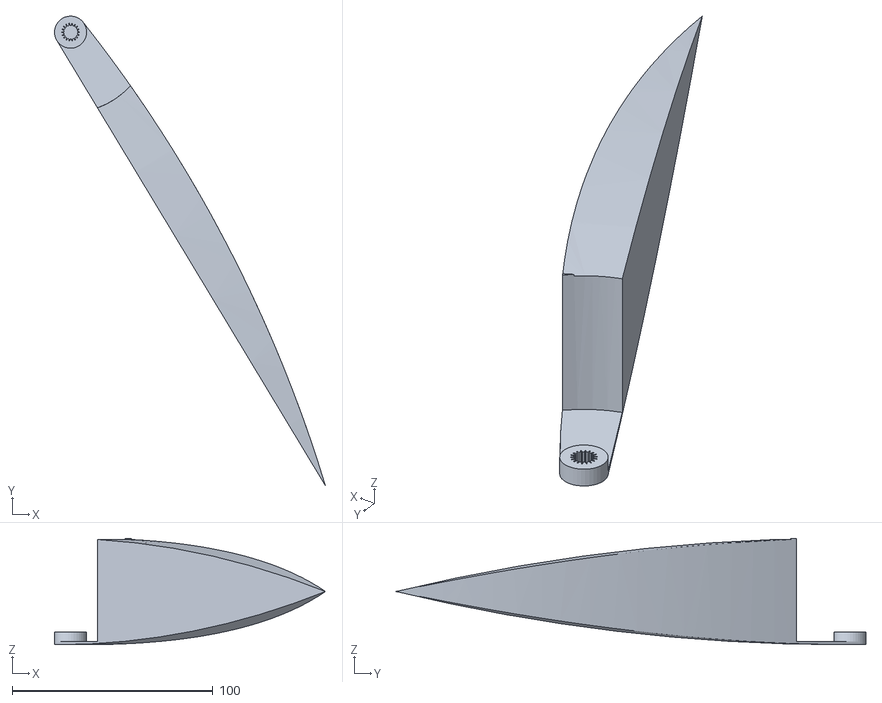
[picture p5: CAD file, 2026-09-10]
CAD/export/Assemblage1 - leg1-1.STL
135.0 x 234.0 x 53.0

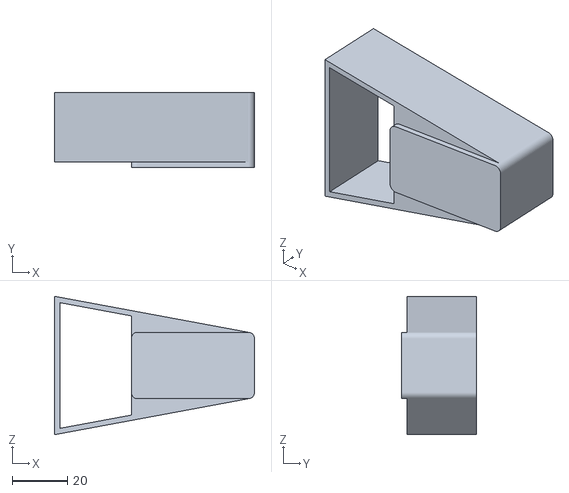
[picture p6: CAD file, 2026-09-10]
CAD/export/Assemblage1 - base-1.STL
72.3 x 27.0 x 50.0

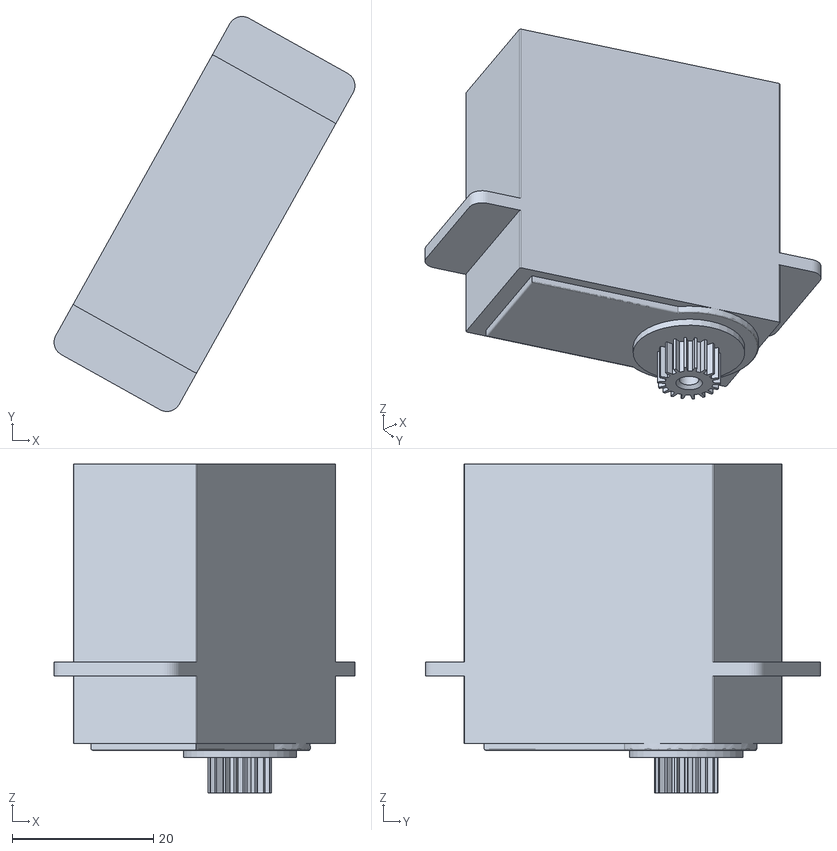
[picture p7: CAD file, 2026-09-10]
CAD/export/Assemblage1 - SERVO-3.STL
42.6 x 55.9 x 46.5

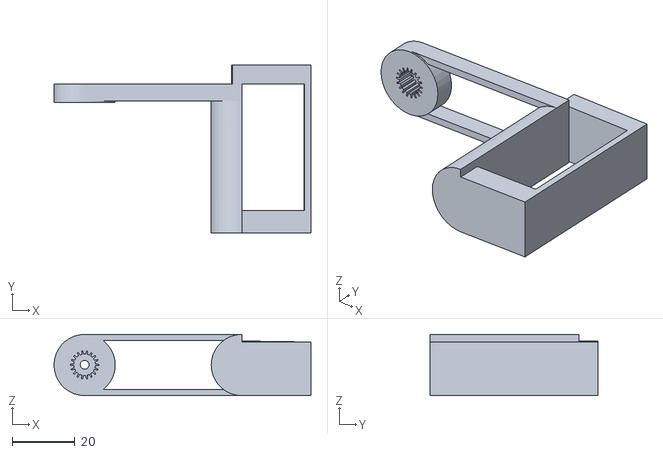
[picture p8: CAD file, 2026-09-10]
CAD/export/Assemblage1 - articulation 1-1.STL
81.7 x 53.5 x 19.5

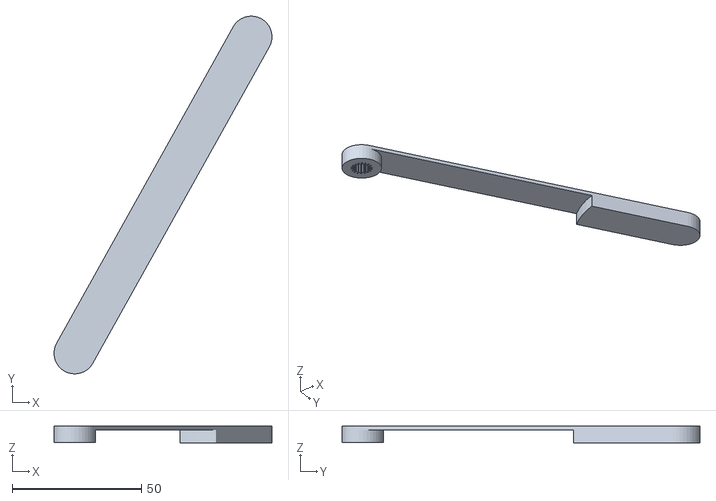
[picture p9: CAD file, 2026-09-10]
CAD/export/Assemblage1 - articulation 2-1.STL
84.2 x 138.2 x 6.50

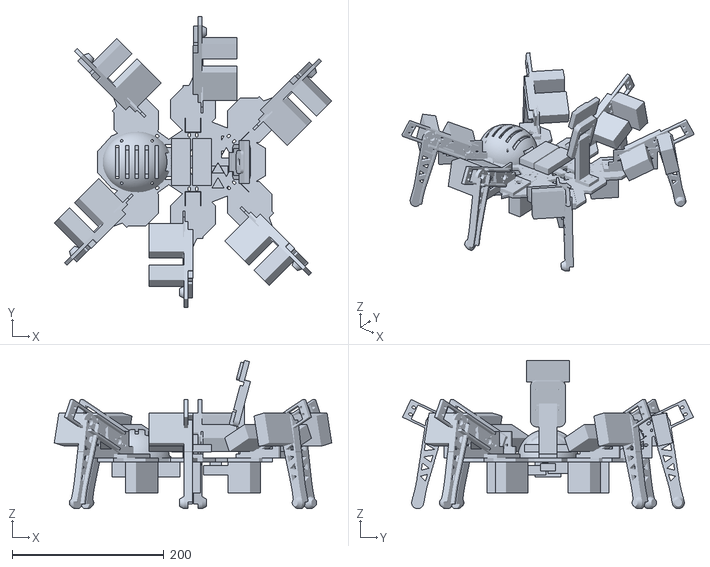
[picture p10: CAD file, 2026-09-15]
CAD/generated/assembly.stl
366.4 x 384.1 x 196.0

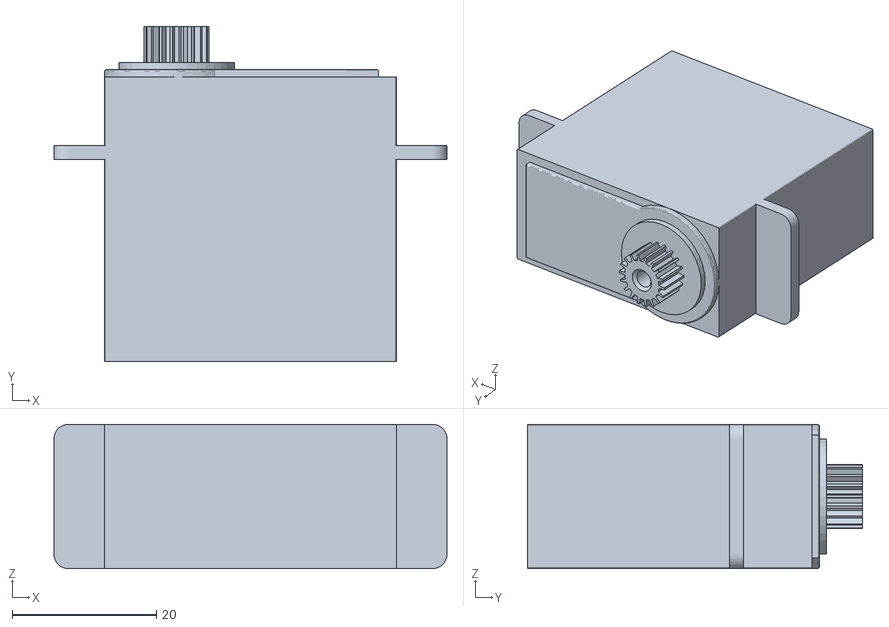
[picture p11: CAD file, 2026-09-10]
CAD/export/Assemblage1 - SERVO-1.STL
54.5 x 46.5 x 20.0

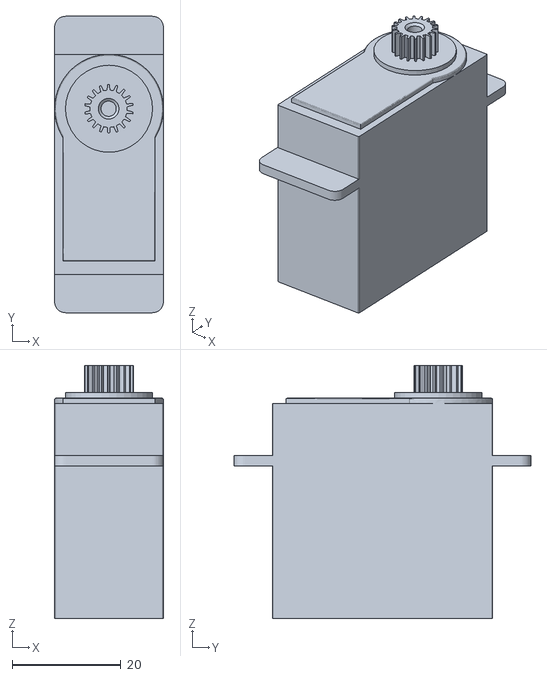
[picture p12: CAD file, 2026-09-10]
CAD/export/Assemblage1 - SERVO-2.STL
20.0 x 54.5 x 46.5

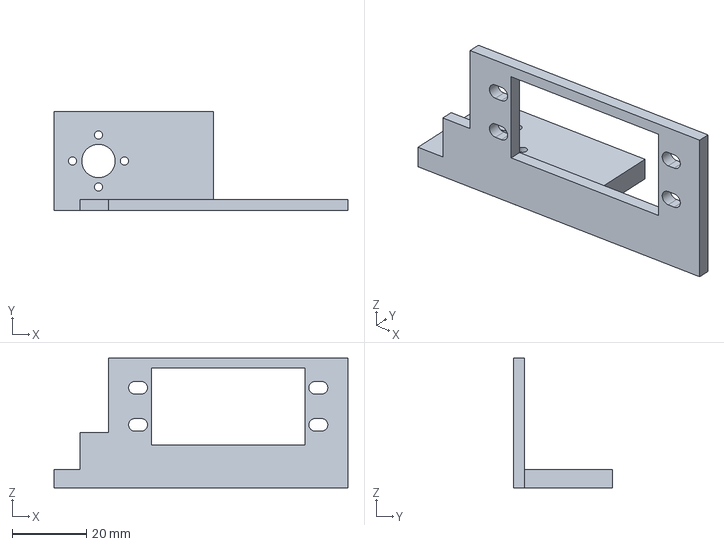
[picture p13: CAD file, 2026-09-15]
CAD/generated/coxa_link.step
79.3 x 26.8 x 35.0 mm

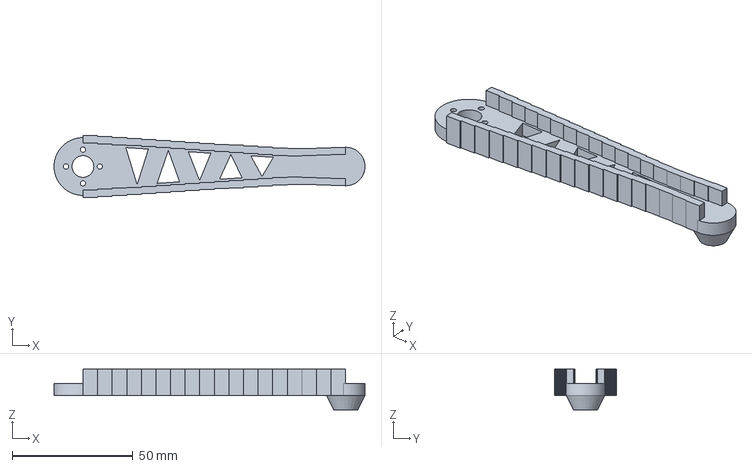
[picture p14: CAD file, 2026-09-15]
CAD/generated/tibia.step
129.0 x 25.6 x 17.0 mm

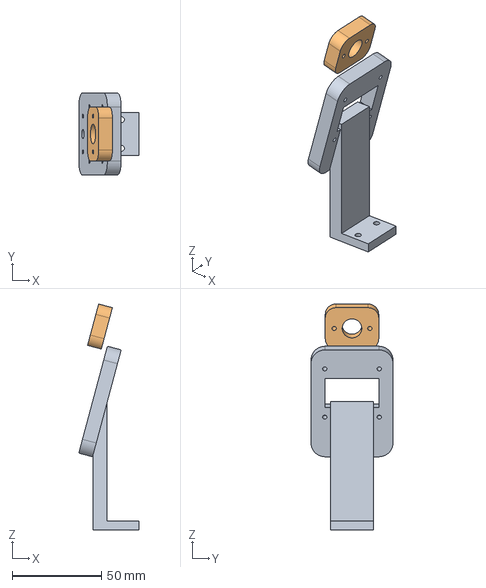
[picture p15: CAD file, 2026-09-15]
CAD/generated/head.step
33.9 x 46.0 x 126.6 mm

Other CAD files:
CAD/leg.SLDPRT
CAD/SERVO.SLDPRT
CAD/articulation 1.SLDPRT
CAD/articulation 2.SLDPRT
CAD/base.SLDPRT
CAD/Assemblage1.SLDASM
CAD/generated/abdomen.step
CAD/generated/abdomen.stl
CAD/generated/body.step
CAD/generated/body.stl
CAD/generated/coxa_link.stl
CAD/generated/femur_link.step
CAD/generated/femur_link.stl
CAD/generated/head.stl
CAD/generated/tibia.stl

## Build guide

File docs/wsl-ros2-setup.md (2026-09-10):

# Installer la chaîne de simulation : WSL2 + ROS 2 Jazzy + Gazebo Harmonic

Gazebo est un outil Linux. Sur Windows 11 il tourne dans WSL2, avec fenêtres
et accélération GPU via WSLg (intégré). La machine a ce qu'il faut :
virtualisation active, RTX 2000 Ada, 32 Go de RAM, 677 Go libres.

## 1. WSL — droits administrateur requis

Il faut un compte administrateur (sur un poste d'entreprise, souvent l'IT).
Dans un PowerShell **ouvert en administrateur** :

```
wsl --install -d Ubuntu-24.04
```

Redémarrer quand on le demande. Au premier lancement d'Ubuntu, choisir un nom
d'utilisateur et un mot de passe Linux. Vérifier ensuite depuis un PowerShell
normal :

```
wsl -l -v
```

`Ubuntu-24.04` doit apparaître en `VERSION 2`.

## 2. ROS 2 Jazzy + Gazebo Harmonic — dans Ubuntu

Le duo LTS (support jusqu'en 2029). Dans le terminal Ubuntu :

```bash
sudo apt update && sudo apt install -y software-properties-common curl
sudo add-apt-repository -y universe
sudo curl -sSL https://raw.githubusercontent.com/ros/rosdistro/master/ros.key \
  -o /usr/share/keyrings/ros-archive-keyring.gpg
echo "deb [arch=$(dpkg --print-architecture) signed-by=/usr/share/keyrings/ros-archive-keyring.gpg] \
  http://packages.ros.org/ros2/ubuntu $(. /etc/os-release && echo $UBUNTU_CODENAME) main" \
  | sudo tee /etc/apt/sources.list.d/ros2.list > /dev/null
sudo apt update && sudo apt install -y \
  ros-jazzy-desktop ros-dev-tools \
  ros-jazzy-ros-gz ros-jazzy-gz-ros2-control \
  ros-jazzy-ros2-control ros-jazzy-ros2-controllers \
  ros-jazzy-xacro ros-jazzy-joint-state-publisher-gui \
  ros-jazzy-teleop-twist-keyboard
echo 'source /opt/ros/jazzy/setup.bash' >> ~/.bashrc
```

`ros-jazzy-ros-gz` tire Gazebo Harmonic, la version appariée à Jazzy.
Compter ~10 Go et une vingtaine de minutes.

## 3. Le workspace

Compiler sur `/mnt/c/...` est lent (système de fichiers traversant). On clone
le dépôt dans le système de fichiers Linux :

```bash
mkdir -p ~/ros2_ws/src
cd ~/ros2_ws/src
git clone /mnt/c/Users/<toi>/Documents/Robot hexapod   # ou git clone https://github.com/Brun0zinh0/Hexabeast.git hexapod
cd ~/ros2_ws
sudo rosdep init 2>/dev/null; rosdep update
rosdep install --from-paths src --ignore-src -r -y
colcon build --symlink-install
source install/setup.bash
```

Les paquets sont dans `hexapod/ros2_ws/src/` ; colcon les trouve en
parcourant `src/` récursivement.

## 4. Lancer

```bash
ros2 launch hexapod_description sim.launch.py
```

Gazebo s'ouvre sur le parcours (trottoir, colline), le robot apparaît et se
met debout. Dans un second terminal :

```bash
ros2 run teleop_twist_keyboard teleop_twist_keyboard
```

`i` avance, `,` recule, `j`/`l` tournent, `J`/`L` marchent en crabe.

Pour vérifier le modèle seul, sans Gazebo, avec des curseurs par articulation :

```bash
ros2 launch hexapod_description display.launch.py
```

## 5. Regénérer la description après un changement de géométrie

Sur Windows comme sur Linux, Python suffit :

```bash
python tools/gen_urdf.py --check
```

`--check` fait passer la cinématique directe par la chaîne d'articulations de
l'URDF et la compare à l'IK : une erreur de signe d'axe est détectée avant
que Gazebo ne la voie.

## Points à vérifier au premier lancement

- `gz topic -l` doit lister les capteurs (`.../sensor/imu/imu`,
  `.../sensor/FL_foot/contact`, …). Si un pont reste muet, ajuster les noms
  dans `config/bridge.yaml`.
- `ros2 control list_controllers` doit montrer `leg_controller` et
  `joint_state_broadcaster` en `active`.
- Si le rendu Gazebo est noir ou plante sous WSLg, ajouter
  `--render-engine ogre` (moteur v1) aux `gz_args`.

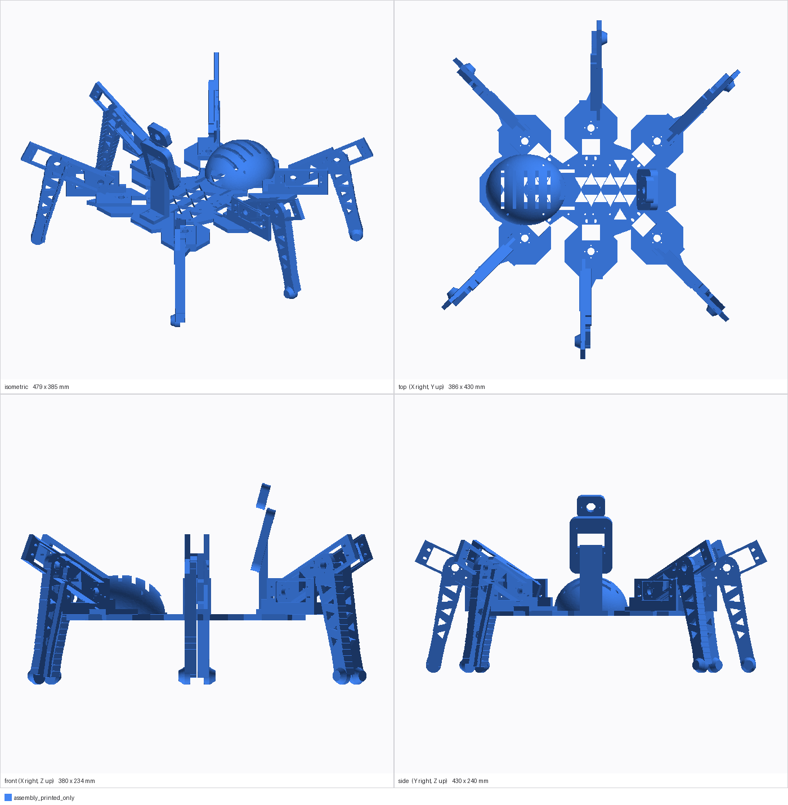
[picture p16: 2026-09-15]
docs/robot-assembly.png

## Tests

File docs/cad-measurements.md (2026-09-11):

# CAD leg, measured

First leg modelled in SolidWorks on 2026-09-10 and measured from the STL/STEP
exports in `CAD/export/`. Everything here is measured, not estimated.

## Link lengths

Joint axes were found by fitting cylinders to the exported meshes, which share
one assembly frame. The axes are the **bores in the driven parts** - each sits
about 7 mm from the servo case's own rounded end (r = 10.37 mm), which is the
feature a naive fit latches onto instead.

The leg is drawn in a vertical plane with **Y up**: the coxa axis is vertical,
the femur and knee axes horizontal along Z.

| Link | Axis to axis | Placeholder it replaces | Ratio |
|---|---|---|---|
| COXA | 59.8 mm | 30 mm | 2.0x |
| FEMUR | 139.9 mm | 60 mm | 2.3x |
| TIBIA | 259.0 mm | 90 mm | 2.9x |
| **Total reach** | **458.7 mm** | 180 mm | **2.5x** |

Joint axes in assembly coordinates:

| Joint | Direction | Passes through |
|---|---|---|
| coxa | Y (vertical) | x = 40.2, z = 63.5 |
| femur | Z (horizontal) | x = 100.0, y = 104.6 |
| knee | Z (horizontal) | x = 168.5, y = 226.6 |
| foot tip | - | (295.4, 0.9, 62.8) |

## Masses

STL volume is exact; mass depends on what you print it at. A 3D-printed part
is never solid - perimeters and skins are, the middle is not - so effective
density lands near `0.3 + 0.7 x infill`.

| Part | Volume | Solid PLA | at 30 % infill |
|---|---|---|---|
| leg1 (tibia) | 133.65 cm3 | 165.7 g | 76 g |
| base | 21.38 cm3 | 26.5 g | 12 g |
| articulation 1 | 16.26 cm3 | 20.2 g | 9 g |
| articulation 2 | 8.34 cm3 | 10.3 g | 5 g |
| **printed per leg** | **179.6 cm3** | 222.7 g | **102 g** |
| 3x DT996 servo | - | **165 g** | 165 g |
| **total per leg** | | | **267 g** |

The servo STL reports 41.6 g at PLA density. Ignore it - a DT996 is motor,
metal gears and a PCB, and weighs **55 g**. Only printed parts may take the
plastic density.

## The problem: this leg is proportioned for stronger servos

> **Correction (2026-09-11).** An earlier version of this file said 4.4x over
> budget. That was wrong. `scale_torque.py`'s `reach` is the **stance lever
> arm** - the horizontal coxa-axis-to-foot distance while standing - and I fed
> it the fully-extended link chain instead, overstating torque by about 1.9x.
> The corrected figures are below.

Torque is `C x mass x g x stance_reach`, calibrated against the 0.83 N.m the
Phase-1 sim measured while climbing. Two things follow.

**The limit is stance reach, not link length.** At ~1.34 kg all-up, the DT996
ceiling is **147 mm of stance reach**, whatever the links measure - a longer
leg can always stand more tucked, trading ground clearance for torque.

**The leg as drawn** stands at 242 mm reach with a sim-like tuck, needing
2.61 N.m against 1.12 N.m usable: **2.3x over**, not 4.4x.

## Uniform scaling is the wrong operation

A DT996 is 40.7 x 19.7 x 42.9 mm at every scale. The leg is a mix of *length*
features, which should scale, and *servo interface* features, which must not.
Shrinking both together fails from below long before torque becomes the issue:

| Scale | Links (mm) | Stance | Torque | articulation 1 | Verdict |
|---|---|---|---|---|---|
| 33 % | 20 / 46 / 86 | 80 mm | 0.59 N.m (1.9x margin) | **27 mm** | unbuildable - must bolt a 41 mm servo |
| 40 % | 24 / 56 / 104 | 97 mm | 0.73 N.m | **33 mm** | unbuildable |
| 50 % | 30 / 70 / 130 | 121 mm | 0.94 N.m | 41 mm | exactly servo-length, no wall |
| 55 % | 33 / 77 / 142 | 132 mm | ~1.09 N.m | 45 mm | workable |
| 60 % | 36 / 84 / 155 | 145 mm | 1.17 N.m | 49 mm | over torque |

At 33 % the *torque is comfortable* - 0.59 N.m with 1.9x margin. What fails is
geometry: articulation 1 carries the femur servo and currently spans 81.7 mm
around it. At 27 mm it is smaller than the servo it must hold.

The usable window for uniform scaling is roughly 55-58 %, which is thin. The
better move is to scale the link *lengths* to the torque budget and redraw the
brackets at servo size.

## Decided: 42 % of the CAD

Scaled on 2026-09-11, keeping the DT996 servos. `robot_config.py` now holds:

| | Value | Was (placeholder) |
|---|---|---|
| Links | 25 / 59 / 109 mm | 30 / 60 / 90 |
| Proportions | 1 : 2.36 : 4.36 | 1 : 2 : 3 |
| Link chain | 193 mm | 180 mm |
| Stance reach | 102 mm | 95 mm |
| Stand height | 81 mm | 75 mm |
| Foot span | 344 mm | 330 mm |
| All-up mass | 1.61 kg | 1.32 kg |
| Servo centres | 0 / 45 / -105 deg | 0 / 22 / -94 |

The proportions are the CAD's to within a percent, so this is the same leg at
42 %, not a different design. Torque lands at 0.54 N.m standing and 0.94 N.m
climbing against 1.12 N.m usable - a **1.19x margin**.

Why 42 % and not the 33 % first asked for: at 33 % the torque was never the
problem (0.59 N.m, 1.9x margin) - `articulation 1` fell to 27 mm while still
needing to bolt on a 40.7 mm servo. 42 % puts it at 34 mm, which still means
**redrawing the brackets around the servo** rather than scaling them. The link
*lengths* scale; the *servo interfaces* cannot.

Worst-case joint excursions from centre are coxa 44, femur 62, tibia 68 deg,
all inside the 80 deg of usable travel - so the horns can be fitted at the
centres above and every walking pose is reachable.

### What still has to change in CAD

- `articulation 1` and `articulation 2`: redraw at 42 % **length**, servo
  mounting features at full size.
- `leg1` (tibia): 259 -> 109 mm. This one is pure length, so it scales cleanly.
- The body does not exist yet. `LEGS` still assumes hip axes 70 mm off centre;
  that is the number to design the chassis around, or change and re-run.

Nothing about the servo calibration survives a geometry change - re-run
`python tools/check_ik.py` and copy the new midpoints into `JOINT_CENTER_DEG`
before fitting a single horn.

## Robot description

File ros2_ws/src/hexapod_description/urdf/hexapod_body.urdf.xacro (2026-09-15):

<?xml version="1.0"?>
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
<robot xmlns:xacro="http://www.ros.org/wiki/xacro" name="hexapod_body">
  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
  <link name="base_link">
    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
    <inertial>
      <origin xyz="0.00000 0.00000 0.00000"/>
      <mass value="0.737"/>
      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
    </inertial>
  </link>

  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
  <joint name="FL_coxa" type="revolute">
    <parent link="base_link"/>
    <child link="FL_coxa_link"/>
    <origin xyz="0.07500 0.05500 0.00000" rpy="0.00000 0.00000 0.78540"/>
    <axis xyz="0 0 1"/>
    <limit lower="-1.3963" upper="1.3963" effort="1.1" velocity="6.5"/>
    <dynamics damping="0.01"/>
  </joint>
  <link name="FL_coxa_link">
    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
    <inertial>
      <origin xyz="0.01250 0.00000 0.00000"/>
      <mass value="0.065"/>
      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
    </inertial>
  </link>
  <joint name="FL_femur" type="revolute">
    <parent link="FL_coxa_link"/>
    <child link="FL_femur_link"/>
    <origin xyz="0.02500 0.00000 0.00000" rpy="0.00000 0.00000 0.00000"/>
    <axis xyz="0 -1 0"/>
    <limit lower="-0.6109" upper="2.1817" effort="1.1" velocity="6.5"/>
    <dynamics damping="0.01"/>
  </joint>
  <link name="FL_femur_link">
    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
    <inertial>
      <origin xyz="0.02950 0.00000 0.00000"/>
      <mass value="0.063"/>
      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
    </inertial>
  </link>
  <joint name="FL_tibia" type="revolute">
    <parent link="FL_femur_link"/>
    <child link="FL_tibia_link"/>
    <origin xyz="0.05900 0.00000 0.00000" rpy="0.00000 0.00000 0.00000"/>
    <axis xyz="0 -1 0"/>
    <limit lower="-3.2289" upper="-0.4363" effort="1.1" velocity="6.5"/>
    <dynamics damping="0.01"/>
  </joint>
  <link name="FL_tibia_link">
    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
    <inertial>
      <origin xyz="0.05450 0.00000 0.00000"/>
      <mass value="0.008"/>
      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
    </inertial>
  </link>

  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
  <joint name="ML_coxa" type="revolute">
    <parent link="base_link"/>
    <child link="ML_coxa_link"/>
    <origin xyz="0.00000 0.07000 0.00000" rpy="0.00000 0.00000 1.57080"/>
    <axis xyz="0 0 1"/>
    <limit lower="-1.3963" upper="1.3963" effort="1.1" velocity="6.5"/>
    <dynamics damping="0.01"/>
  </joint>
  <link name="ML_coxa_link">
    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
    <inertial>
      <origin xyz="0.01250 0.00000 0.00000"/>
      <mass value="0.065"/>
      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
    </inertial>
  </link>
  <joint name="ML_femur" type="revolute">
    <parent link="ML_coxa_link"/>
    <child link="ML_femur_link"/>
    <origin xyz="0.02500 0.00000 0.00000" rpy="0.00000 0.00000 0.00000"/>
    <axis xyz="0 -1 0"/>
    <limit lower="-0.6109" upper="2.1817" effort="1.1" velocity="6.5"/>
    <dynamics damping="0.01"/>
  </joint>
  <link name="ML_femur_link">
    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
    <inertial>
      <origin xyz="0.02950 0.00000 0.00000"/>
      <mass value="0.063"/>
      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
    </inertial>
  </link>
  <joint name="ML_tibia" type="revolute">
    <parent link="ML_femur_link"/>
    <child link="ML_tibia_link"/>
    <origin xyz="0.05900 0.00000 0.00000" rpy="0.00000 0.00000 0.00000"/>
    <axis xyz="0 -1 0"/>
    <limit lower="-3.2289" upper="-0.4363" effort="1.1" velocity="6.5"/>
    <dynamics damping="0.01"/>
  </joint>
  <link name="ML_tibia_link">
    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
    <inertial>
      <origin xyz="0.05450 0.00000 0.00000"/>
      <mass value="0.008"/>
      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
    </inertial>
  </link>

  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
  <joint name="RL_coxa" type="revolute">
    <parent link="base_link"/>
    <child link="RL_coxa_link"/>
    <origin xyz="-0.07500 0.05500 0.00000" rpy="0.00000 0.00000 2.35619"/>
    <axis xyz="0 0 1"/>
    <limit lower="-1.3963" upper="1.3963" effort="1.1" velocity="6.5"/>
    <dynamics damping="0.01"/>
  </joint>
  <link name="RL_coxa_link">
    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
    <inertial>
      <origin xyz="0.01250 0.00000 0.00000"/>
      <mass value="0.065"/>
      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
    </inertial>
  </link>
  <joint name="RL_femur" type="revolute">
    <parent link="RL_coxa_link"/>
    <child link="RL_femur_link"/>
    <origin xyz="0.02500 0.00000 0.00000" rpy="0.00000 0.00000 0.00000"/>
    <axis xyz="0 -1 0"/>
    <limit lower="-0.6109" upper="2.1817" effort="1.1" velocity="6.5"/>
    <dynamics damping="0.01"/>
  </joint>
  <link name="RL_femur_link">
    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
    <inertial>
      <origin xyz="0.02950 0.00000 0.00000"/>
      <mass value="0.063"/>
      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
    </inertial>
  </link>
  <joint name="RL_tibia" type="revolute">
    <parent link="RL_femur_link"/>
    <child link="RL_tibia_link"/>
    <origin xyz="0.05900 0.00000 0.00000" rpy="0.00000 0.00000 0.00000"/>
    <axis xyz="0 -1 0"/>
    <limit lower="-3.2289" upper="-0.4363" effort="1.1" velocity="6.5"/>
    <dynamics damping="0.01"/>
  </joint>
  <link name="RL_tibia_link">
    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
    <inertial>
      <origin xyz="0.05450 0.00000 0.00000"/>
      <mass value="0.008"/>
      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
    </inertial>
  </link>

  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
  <joint name="FR_coxa" type="revolute">
    <parent link="base_link"/>
    <child link="FR_coxa_link"/>
    <origin xyz="0.07500 -0.05500 0.00000" rpy="0.00000 0.00000 -0.78540"/>
    <axis xyz="0 0 1"/>
    <limit lower="-1.3963" upper="1.3963" effort="1.1" velocity="6.5"/>
    <dynamics damping="0.01"/>
  </joint>
  <link name="FR_coxa_link">
    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
    <inertial>
      <origin xyz="0.01250 0.00000 0.00000"/>
      <mass value="0.065"/>
      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
    </inertial>
  </link>
  <joint name="FR_femur" type="revolute">
    <parent link="FR_coxa_link"/>
    <child link="FR_femur_link"/>
    <origin xyz="0.02500 0.00000 0.00000" rpy="0.00000 0.00000 0.00000"/>
    <axis xyz="0 -1 0"/>
    <limit lower="-0.6109" upper="2.1817" effort="1.1" velocity="6.5"/>
    <dynamics damping="0.01"/>
  </joint>
  <link name="FR_femur_link">
    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
    <inertial>
      <origin xyz="0.02950 0.00000 0.00000"/>
      <mass value="0.063"/>
      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
    </inertial>
  </link>
  <joint name="FR_tibia" type="revolute">
    <parent link="FR_femur_link"/>
    <child link="FR_tibia_link"/>
    <origin xyz="0.05900 0.00000 0.00000" rpy="0.00000 0.00000 0.00000"/>
    <axis xyz="0 -1 0"/>
    <limit lower="-3.2289" upper="-0.4363" effort="1.1" velocity="6.5"/>
    <dynamics damping="0.01"/>
  </joint>
  <link name="FR_tibia_link">
    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
    <inertial>
      <origin xyz="0.05450 0.00000 0.00000"/>
      <mass value="0.008"/>
      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
    </inertial>
  </link>

  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
  <joint name="MR_coxa" type="revolute">
    <parent link="base_link"/>
    <child link="MR_coxa_link"/>
    <origin xyz="0.00000 -0.07000 0.00000" rpy="0.00000 0.00000 -1.57080"/>
    <axis xyz="0 0 1"/>
    <limit lower="-1.3963" upper="1.3963" effort="1.1" velocity="6.5"/>
    <dynamics damping="0.01"/>
  </joint>
  <link name="MR_coxa_link">
    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
    <inertial>
      <origin xyz="0.01250 0.00000 0.00000"/>
      <mass value="0.065"/>
      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
    </inertial>
  </link>
  <joint name="MR_femur" type="revolute">
    <parent link="MR_coxa_link"/>
    <child link="MR_femur_link"/>
    <origin xyz="0.02500 0.00000 0.00000" rpy="0.00000 0.00000 0.00000"/>
    <axis xyz="0 -1 0"/>
    <limit lower="-0.6109" upper="2.1817" effort="1.1" velocity="6.5"/>
    <dynamics damping="0.01"/>
  </joint>
  <link name="MR_femur_link">
    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
    <inertial>
      <origin xyz="0.02950 0.00000 0.00000"/>
      <mass value="0.063"/>
      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
    </inertial>
  </link>
  <joint name="MR_tibia" type="revolute">
    <parent link="MR_femur_link"/>
    <child link="MR_tibia_link"/>
    <origin xyz="0.05900 0.00000 0.00000" rpy="0.00000 0.00000 0.00000"/>
    <axis xyz="0 -1 0"/>
    <limit lower="-3.2289" upper="-0.4363" effort="1.1" velocity="6.5"/>
    <dynamics damping="0.01"/>
  </joint>
  <link name="MR_tibia_link">
    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
    <inertial>
      <origin xyz="0.05450 0.00000 0.00000"/>
      <mass value="0.008"/>
      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
    </inertial>
  </link>
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

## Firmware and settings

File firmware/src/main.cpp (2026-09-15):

// Hexabeast firmware - stage 1: servos, calibration and the gait loop.
//
// WiFi, the camera and the FPV link come next; this stage is everything you can
// test on a bench with a board, two PCA9685s and as few as one servo.
//
// It boots relaxed. Nothing moves until you say so, because the first thing a
// miswired hexapod does on power-up is fold a leg through its own chassis.
//
// Serial console at 115200 - send `?` for the command list.

#include <Arduino.h>

#include "gait.h"
#include "leg_ik.h"
#include "robot_geometry.h"
#include "servo_bus.h"

using namespace robot;

// --- wiring ------------------------------------------------------------------
// I2C for both PCA9685s, the IMU and the foot-switch expander. The ESP32-S3's
// GPIO matrix puts I2C on almost any free pin; avoid 19/20, which are USB D-/D+.
constexpr int PIN_SDA = 1;
constexpr int PIN_SCL = 2;

constexpr uint32_t LOOP_HZ = 50;             // servo update rate
constexpr uint32_t LOOP_US = 1000000 / LOOP_HZ;
constexpr float STARTUP_TIME = 2.0f;         // ease from centre into stance
constexpr float BLEND_RATE = 4.0f;           // how fast legs settle when stopped
constexpr float MAX_SPEED = 0.10f;           // m/s
constexpr float MAX_TURN = 1.0f;             // rad/s

// Watchdog on the command channel. A joystick that goes quiet - dropped WiFi,
// closed browser - must stop the robot rather than leave it walking away.
constexpr uint32_t CMD_TIMEOUT_MS = 500;

enum class Mode { Idle, Calibrate, Run };

ServoBus bus;
Mode mode = Mode::Idle;

float cmd_vx = 0, cmd_vy = 0, cmd_wz = 0;
uint32_t cmd_stamp_ms = 0;
float phase = 0, blend = 0, startup = 0;
int sel_joint = 0;                            // calibration cursor
uint32_t last_loop_us = 0;

static float move_toward(float v, float target, float step) {
  if (fabsf(target - v) <= step) return target;
  return v + (target > v ? step : -step);
}

static void help() {
  Serial.println();
  Serial.println(F("Hexabeast - commands"));
  Serial.println(F("  ?          this list"));
  Serial.println(F("  e / x      enable output / relax (x is the panic key)"));
  Serial.println(F("  c          all servos to mechanical centre"));
  Serial.println(F("  k          calibration mode"));
  Serial.println(F("  r          run mode (gait)"));
  Serial.println(F("  i          status"));
  Serial.println(F("calibration:"));
  Serial.println(F("  j<n>       select joint 0-17      n / p   next / previous"));
  Serial.println(F("  + / -      trim +/-10 us          > / <   trim +/-2 us"));
  Serial.println(F("  f          flip this joint's direction"));
  Serial.println(F("  s          save calibration to NVS"));
  Serial.println(F("run mode:"));
  Serial.println(F("  w<vx>,<vy>,<wz>   e.g. w0.08,0,0   walk forward"));
  Serial.println(F("  h          halt (zero command)"));
  Serial.println();
}

static void status() {
  Serial.printf("mode=%s output=%s phase=%.2f blend=%.2f\n",
                mode == Mode::Idle ? "idle" : mode == Mode::Calibrate ? "calib" : "run",
                bus.enabled() ? "ON" : "off", phase, blend);
  Serial.printf("cmd vx=%.3f vy=%.3f wz=%.3f (%lu ms ago)\n",
                cmd_vx, cmd_vy, cmd_wz, (unsigned long)(millis() - cmd_stamp_ms));
  Serial.printf("selected joint %d (%s)  ch=%u/%u dir=%+d trim=%d us  last=%u us\n",
                sel_joint, JOINT_NAMES[sel_joint], SERVOS[sel_joint].board,
                SERVOS[sel_joint].channel, bus.dir(sel_joint), bus.trim(sel_joint),
                bus.last_us(sel_joint));
  int clamped = 0;
  for (int j = 0; j < NUM_JOINTS; ++j) if (bus.clamped(j)) ++clamped;
  if (clamped) Serial.printf("WARNING %d joint(s) clamped at travel limit\n", clamped);
}

static void select(int j) {
  sel_joint = (j + NUM_JOINTS) % NUM_JOINTS;
  Serial.printf("joint %d (%s) ch=%u/%u dir=%+d trim=%d\n", sel_joint,
                JOINT_NAMES[sel_joint], SERVOS[sel_joint].board,
                SERVOS[sel_joint].channel, bus.dir(sel_joint), bus.trim(sel_joint));
}

// Hold the selected joint at centre while its trim is adjusted, so the horn can
// be seen to line up. Everything else stays where it was.
static void refresh_calibration_pose() {
  const float d2r = kPi / 180.0f;
  bus.set_joint(sel_joint, CENTER_DEG[sel_joint % 3] * d2r);
}

static void handle(const String& line) {
  if (line.length() == 0) return;
  const char c = line[0];
  const String arg = line.substring(1);

  switch (c) {
    case '?': help(); break;
    case 'i': status(); break;
    case 'e':
      bus.enable(true);
      startup = 0;
      Serial.println(F("output ENABLED - ramping to pose"));
      break;
    case 'x':
      bus.relax();
      mode = Mode::Idle;
      Serial.println(F("relaxed"));
      break;
    case 'c':
      bus.center_all();
      Serial.println(F("all servos at mechanical centre"));
      break;
    case 'k':
      mode = Mode::Calibrate;
      bus.center_all();
      Serial.println(F("calibration mode - fit horns at this pose"));
      select(sel_joint);
      break;
    case 'r':
      mode = Mode::Run;
      startup = 0;
      Serial.println(F("run mode"));
      break;
    case 'j': select(arg.toInt()); refresh_calibration_pose(); break;
    case 'n': select(sel_joint + 1); refresh_calibration_pose(); break;
    case 'p': select(sel_joint - 1); refresh_calibration_pose(); break;
    case '+': bus.set_trim(sel_joint, bus.trim(sel_joint) + 10); refresh_calibration_pose();
              Serial.printf("trim %d us\n", bus.trim(sel_joint)); break;
    case '-': bus.set_trim(sel_joint, bus.trim(sel_joint) - 10); refresh_calibration_pose();
              Serial.printf("trim %d us\n", bus.trim(sel_joint)); break;
    case '>': bus.set_trim(sel_joint, bus.trim(sel_joint) + 2); refresh_calibration_pose();
              Serial.printf("trim %d us\n", bus.trim(sel_joint)); break;
    case '<': bus.set_trim(sel_joint, bus.trim(sel_joint) - 2); refresh_calibration_pose();
              Serial.printf("trim %d us\n", bus.trim(sel_joint)); break;
    case 'f':
      bus.set_dir(sel_joint, -bus.dir(sel_joint));
      refresh_calibration_pose();
      Serial.printf("direction %+d\n", bus.dir(sel_joint));
      break;
    case 's': bus.save_calibration(); break;
    case 'h': cmd_vx = cmd_vy = cmd_wz = 0; cmd_stamp_ms = millis(); break;
    case 'w': {
      const int c1 = arg.indexOf(',');
      const int c2 = arg.indexOf(',', c1 + 1);
      if (c1 < 0 || c2 < 0) { Serial.println(F("usage: w<vx>,<vy>,<wz>")); break; }
      cmd_vx = clampf(arg.substring(0, c1).toFloat(), -MAX_SPEED, MAX_SPEED);
      cmd_vy = clampf(arg.substring(c1 + 1, c2).toFloat(), -MAX_SPEED, MAX_SPEED);
      cmd_wz = clampf(arg.substring(c2 + 1).toFloat(), -MAX_TURN, MAX_TURN);
      cmd_stamp_ms = millis();
      Serial.printf("cmd %.3f %.3f %.3f\n", cmd_vx, cmd_vy, cmd_wz);
      break;
    }
    default: Serial.println(F("unknown - send ? for help"));
  }
}

static void read_serial() {
  static String line;
  while (Serial.available()) {
    const char ch = (char)Serial.read();
    if (ch == '\n' || ch == '\r') {
      if (line.length()) { handle(line); line = ""; }
    } else if (line.length() < 64) {
      line += ch;
    }
  }
}

static void step_gait(float dt) {
  // A command that has gone stale stops the robot. This is the same guarantee
  // the WiFi link will need, so it lives here rather than in the transport.
  if (millis() - cmd_stamp_ms > CMD_TIMEOUT_MS) {
    cmd_vx = cmd_vy = cmd_wz = 0;
  }

  startup = fminf(startup + dt / STARTUP_TIME, 1.0f);
  const bool moving = fabsf(cmd_vx) > 1e-3f || fabsf(cmd_vy) > 1e-3f ||
                      fabsf(cmd_wz) > 1e-3f;
  blend = move_toward(blend, moving ? 1.0f : 0.0f, BLEND_RATE * dt);
  if (blend > 1e-3f) {
    phase = fmodf(phase + dt / CYCLE_TIME, 1.0f);
  }

  for (int leg = 0; leg < NUM_LEGS; ++leg) {
    const Vec3 a = solve_leg(leg, cmd_vx, cmd_vy, cmd_wz, phase, blend);
    // Ease out of the boot pose: interpolate from servo centre to the solved
    // pose over STARTUP_TIME rather than snapping to it.
    const float d2r = kPi / 180.0f;
    const Vec3 eased{
        CENTER_DEG[0] * d2r + (a.x - CENTER_DEG[0] * d2r) * startup,
        CENTER_DEG[1] * d2r + (a.y - CENTER_DEG[1] * d2r) * startup,
        CENTER_DEG[2] * d2r + (a.z - CENTER_DEG[2] * d2r) * startup};
    bus.set_leg(leg, eased);
  }
}

void setup() {
  Serial.begin(115200);
  delay(300);
  Serial.println();
  Serial.println(F("Hexabeast firmware - servos and gait"));
  Serial.printf("geometry %.0f/%.0f/%.0f mm, reach %.0f mm, %d joints\n",
                COXA * 1000, FEMUR * 1000, TIBIA * 1000, REACH * 1000, NUM_JOINTS);

  if (!bus.begin(PIN_SDA, PIN_SCL)) {
    Serial.println(F("!! a PCA9685 is missing. Check the A0 jumper on board 1,"));
    Serial.println(F("!! and that the INA219 has been moved off 0x40."));
  }
  cmd_stamp_ms = millis();
  last_loop_us = micros();
  help();
  Serial.println(F("output is OFF. `e` to enable, `x` to relax at any time."));
}

void loop() {
  read_serial();

  const uint32_t now = micros();
  if (now - last_loop_us < LOOP_US) return;
  const float dt = (now - last_loop_us) * 1e-6f;
  last_loop_us = now;

  if (mode == Mode::Run) step_gait(dt);
}

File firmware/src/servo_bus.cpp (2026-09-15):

#include "servo_bus.h"

#include <Arduino.h>
#include <Preferences.h>
#include <Wire.h>

namespace robot {

namespace {
// PCA9685 registers
constexpr uint8_t MODE1 = 0x00;
constexpr uint8_t MODE2 = 0x01;
constexpr uint8_t LED0_ON_L = 0x06;
constexpr uint8_t ALL_LED_ON_L = 0xFA;
constexpr uint8_t PRESCALE = 0xFE;

constexpr uint8_t MODE1_RESTART = 0x80;
constexpr uint8_t MODE1_AI = 0x20;      // auto-increment, so a channel is one burst
constexpr uint8_t MODE1_SLEEP = 0x10;
constexpr uint8_t MODE2_OUTDRV = 0x04;  // totem pole, not open drain

// Nominal internal oscillator. Clone boards are often 26-27 MHz, which stretches
// every pulse by a few percent; if the centre pose sits visibly off on all 18
// servos at once, measure the real PWM period and correct here rather than
// trimming each servo around the same systematic error.
constexpr float OSC_HZ = 25000000.0f;

constexpr const char* NVS_NAMESPACE = "hexapod";
}  // namespace

bool ServoBus::probe(uint8_t addr) {
  Wire.beginTransmission(addr);
  return Wire.endTransmission() == 0;
}

void ServoBus::write_reg(uint8_t addr, uint8_t reg, uint8_t val) {
  Wire.beginTransmission(addr);
  Wire.write(reg);
  Wire.write(val);
  Wire.endTransmission();
}

bool ServoBus::begin(int sda, int scl, uint32_t i2c_hz) {
  Wire.begin(sda, scl, i2c_hz);

  for (int j = 0; j < NUM_JOINTS; ++j) {
    dir_[j] = SERVOS[j].dir;
    trim_us_[j] = 0;
  }

  ready_ = true;
  for (int b = 0; b < 2; ++b) {
    if (!probe(ADDR[b])) {
      Serial.printf("[servo] PCA9685 at 0x%02X did not respond\n", ADDR[b]);
      ready_ = false;
      continue;
    }
    // Sleep is required before PRESCALE will latch.
    write_reg(ADDR[b], MODE1, MODE1_SLEEP);
    const uint8_t prescale =
        (uint8_t)(roundf(OSC_HZ / (4096.0f * PWM_HZ)) - 1.0f);
    write_reg(ADDR[b], PRESCALE, prescale);
    write_reg(ADDR[b], MODE1, 0x00);
    delayMicroseconds(500);  // oscillator needs time before RESTART
    write_reg(ADDR[b], MODE1, MODE1_RESTART | MODE1_AI);
    write_reg(ADDR[b], MODE2, MODE2_OUTDRV);
    Serial.printf("[servo] PCA9685 0x%02X up, prescale %u (%.1f Hz)\n",
                  ADDR[b], prescale, PWM_HZ);
  }

  relax();  // boot dark - nothing moves until enable(true)
  load_calibration();
  return ready_;
}

void ServoBus::write_pulse(uint8_t board, uint8_t channel, uint16_t us) {
  // 4096 counts span one period; at 50 Hz that is 20000 us, so 0.2048 counts/us.
  const uint16_t counts =
      us == 0 ? 0 : (uint16_t)(us * 4096.0f * PWM_HZ / 1000000.0f);
  const uint8_t reg = LED0_ON_L + 4 * channel;
  Wire.beginTransmission(ADDR[board]);
  Wire.write(reg);
  Wire.write(0x00);              // ON_L  - rising edge at count 0
  Wire.write(0x00);              // ON_H
  Wire.write(counts & 0xFF);     // OFF_L
  Wire.write((counts >> 8) & 0x0F);  // OFF_H
  Wire.endTransmission();
}

void ServoBus::set_joint(int joint, float angle_rad) {
  if (joint < 0 || joint >= NUM_JOINTS) return;

  const int which = joint % 3;  // 0 coxa, 1 femur, 2 tibia
  const float d2r = kPi / 180.0f;

  // Joint angle -> servo angle, measured from the servo's mechanical centre.
  float servo_deg = (angle_rad - CENTER_DEG[which] * d2r) / d2r;

  clamped_[joint] = fabsf(servo_deg) > TRAVEL_DEG;
  servo_deg = clampf(servo_deg, -TRAVEL_DEG, TRAVEL_DEG);

  // Mirror, then convert to a pulse. (MAX-MIN)/RANGE us per degree.
  const float us_per_deg =
      (float)(SERVO_MAX_US - SERVO_MIN_US) / SERVO_RANGE_DEG;
  float us = (float)SERVO_CENTER_US + trim_us_[joint] +
             dir_[joint] * servo_deg * us_per_deg;
  us = clampf(us, (float)SERVO_MIN_US, (float)SERVO_MAX_US);

  last_us_[joint] = (uint16_t)us;
  if (!enabled_ || !ready_) return;
  write_pulse(SERVOS[joint].board, SERVOS[joint].channel, last_us_[joint]);
}

void ServoBus::set_leg(int leg, const Vec3& a) {
  set_joint(3 * leg + 0, a.x);
  set_joint(3 * leg + 1, a.y);
  set_joint(3 * leg + 2, a.z);
}

void ServoBus::center_all() {
  const float d2r = kPi / 180.0f;
  for (int j = 0; j < NUM_JOINTS; ++j) {
    set_joint(j, CENTER_DEG[j % 3] * d2r);
  }
}

void ServoBus::relax() {
  enabled_ = false;
  if (!ready_) return;
  // ALL_LED_OFF_H bit 4 turns every output fully off in one write per board.
  for (int b = 0; b < 2; ++b) {
    Wire.beginTransmission(ADDR[b]);
    Wire.write(ALL_LED_ON_L);
    Wire.write(0x00);
    Wire.write(0x00);
    Wire.write(0x00);
    Wire.write(0x10);
    Wire.endTransmission();
  }
}

void ServoBus::enable(bool on) {
  if (!on) {
    relax();
    return;
  }
  enabled_ = true;
}

void ServoBus::set_trim(int joint, int16_t us) {
  if (joint >= 0 && joint < NUM_JOINTS) trim_us_[joint] = us;
}

void ServoBus::set_dir(int joint, int8_t d) {
  if (joint >= 0 && joint < NUM_JOINTS) dir_[joint] = d >= 0 ? 1 : -1;
}

bool ServoBus::save_calibration() {
  Preferences p;
  if (!p.begin(NVS_NAMESPACE, false)) return false;
  p.putBytes("trim", trim_us_, sizeof(trim_us_));
  p.putBytes("dir", dir_, sizeof(dir_));
  p.end();
  Serial.println("[servo] calibration saved to NVS");
  return true;
}

bool ServoBus::load_calibration() {
  Preferences p;
  if (!p.begin(NVS_NAMESPACE, true)) return false;
  const bool have = p.getBytesLength("trim") == sizeof(trim_us_);
  if (have) {
    p.getBytes("trim", trim_us_, sizeof(trim_us_));
    p.getBytes("dir", dir_, sizeof(dir_));
    Serial.println("[servo] calibration loaded from NVS");
  } else {
    Serial.println("[servo] no saved calibration - using generated defaults");
  }
  p.end();
  return have;
}

}  // namespace robot

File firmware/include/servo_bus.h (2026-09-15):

// Two PCA9685 boards driving 18 servos over one I2C bus.
//
// The PCA9685 generates the 50 Hz pulses in hardware, so servo timing is immune
// to whatever the CPU is doing - which matters once the same chip is also
// encoding JPEG and serving WiFi.
//
// Board 0 sits at 0x40 and carries the left legs, board 1 at 0x41 the right.
// Channel and direction per joint come from robot_geometry.h, generated from
// robot_config.py.
//
// Safety: nothing is driven until enable() is called. A hexapod that snaps to
// its stance pose the instant power arrives can strip a gear or break a link
// before you reach the switch, so boot leaves every output dark and the legs
// limp.
#pragma once

#include <stdint.h>

#include "leg_ik.h"
#include "robot_geometry.h"

namespace robot {

class ServoBus {
 public:
  static constexpr uint8_t ADDR[2] = {0x40, 0x41};
  static constexpr float PWM_HZ = 50.0f;

  /// Bring up I2C and both boards with all outputs off. Returns false if either
  /// board does not acknowledge - almost always the A0 jumper on board 1, or
  /// the INA219 still sitting on 0x40.
  bool begin(int sda, int scl, uint32_t i2c_hz = 400000);

  /// Allow output. Until this is called every write is accepted and ignored,
  /// so the control loop can run and be watched before anything moves.
  void enable(bool on);
  bool enabled() const { return enabled_; }

  /// Command one joint, in radians of JOINT angle (not servo angle). Applies
  /// the servo centre, the mirror direction and the per-joint trim, clamps to
  /// usable travel, and writes the pulse.
  void set_joint(int joint, float angle_rad);

  /// Command a whole leg at once - the three joints in coxa/femur/tibia order.
  void set_leg(int leg, const Vec3& angles);

  /// Every servo to its mechanical centre. This is the pose to fit horns in.
  void center_all();

  /// Cut all pulses; servos go limp. Also what enable(false) does.
  void relax();

  /// Per-joint zero correction in microseconds, persisted to NVS.
  /// Calibration writes these; nothing else should.
  void set_trim(int joint, int16_t us);
  int16_t trim(int joint) const { return trim_us_[joint]; }
  void set_dir(int joint, int8_t dir);
  int8_t dir(int joint) const { return dir_[joint]; }
  bool save_calibration();
  bool load_calibration();

  /// Last pulse written, for diagnostics and the calibration UI.
  uint16_t last_us(int joint) const { return last_us_[joint]; }

  /// True if a joint was clamped on its last write - the command asked for
  /// more travel than the servo has, which means a geometry or gait problem
  /// rather than a servo one.
  bool clamped(int joint) const { return clamped_[joint]; }

 private:
  void write_reg(uint8_t addr, uint8_t reg, uint8_t val);
  void write_pulse(uint8_t board, uint8_t channel, uint16_t us);
  bool probe(uint8_t addr);

  bool enabled_ = false;
  bool ready_ = false;
  int16_t trim_us_[NUM_JOINTS] = {0};
  int8_t dir_[NUM_JOINTS] = {0};
  uint16_t last_us_[NUM_JOINTS] = {0};
  bool clamped_[NUM_JOINTS] = {false};
};

}  // namespace robot

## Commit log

2026-09-09 Phase 0: kinematic hexapod simulation in Godot
    18-servo hexapod (6 legs x coxa/femur/tibia) built simulation-first
    for an ESP32. This is the kinematic stage: the body moves at the
    commanded velocity and the legs are solved to follow, no physics yet.
    - robot_config.gd: geometry, leg layout, tripod groups, PCA9685
    channel map and servo calibration offsets - single source of truth
    - leg_ik.gd / gait.gd: pure inverse kinematics and tripod gait, kept
    free of engine calls so they port straight to C++ for the firmware
    - hexapod.gd / world.gd: rig built procedurally from the config,
    ground grid, chase camera, HUD with servo-limit warnings
    - tools/check_ik.py: IK round-trip test; its joint-tra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
    [plugin.cfg]
2026-09-09 Phase 1: physics simulation with spring-driven servo joints
    The body and every leg link are now rigid bodies in Jolt, chained by
    6-DoF joints locked to one hinge each. Each hinge carries an angular
    spring whose equilibrium is the commanded servo angle; the gait, IK and
    foot targets are unchanged from Phase 0, and body motion now emerges
    from the feet pushing on a real floor.
    Servo model (robot_config.gd):
    - torque and no-load speed from the datasheet; damping derived from
    them as T_stall / w_free - the speed-torque line is a damping
    coefficient, and guessing it high left the swing legs unable to lift
    - stiffness 12.5 N.m/rad, ~4 deg give at rated load
    - reflected rotor inertia on every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
2026-09-09 Pivot to SolidWorks + ROS 2 + Gazebo; archive the Godot simulation
    The plan changes: the robot is designed in SolidWorks and simulated in
    Gazebo Harmonic under ROS 2 Jazzy (WSL2 on this machine). The Godot
    simulation stays in sim/godot as an archive; its servo findings are kept
    in the README and docs/hardware.md.
    ros2_ws/src/hexapod_gait - Python package:
    - robot_config.py is now the single source of truth (ROS frame: X
    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
    [controllers.yaml, course.sdf, hexapod.urdf.xacro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]
2026-09-10 Lock the hardware spec: DT996 servos, 34 cm, ESP32-S3 FPV
    Sizes the robot around the servo actually being bought, and adds the
    electronics needed to fly it from a phone. Renames the project Hexabeast.
    Servo model corrected to the real part. The DT996 is an MG996R form
    factor digital servo advertised at 15 kg.cm (1.49 N.m at 6 V), not the
    11 kg.cm of a genuine MG996R. SERVO_TORQUE is the advertised 6 V figure
    derated 25 % to 1.10 N.m: clones of this class measure nearer 11 kg.cm,
    so the derating and the design margin are one number doing two jobs.
    URDF effort limits follow.
    tools/scale_torque.py answers how big the robot can be, extrapolating
    the 0.83 N.m the Phase-1 sim measured rather tha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
    [hexapod_body.urdf.xacro]
2026-09-10 Add the CAD: first leg, servo and base
    SolidWorks parts for one leg (two articulations), the DT996 servo and
    the body base, plus the assembly. Geometry is not yet reflected in
    robot_config.py - the sim still runs the placeholder 30/60/90 mm chain
    until the axis-to-axis distances are measured off these parts.
    .gitignore gains the SolidWorks working files: ~$ locks, .bak backups
    and journals. The lock files were present while the app had the parts
    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
    [Assemblage1.SLDASM, SERVO.SLDPRT, articulation 1.SLDPRT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]
2026-09-10 Add tools/measure_cad.py to pull real numbers out of CAD exports
    Bridges the CAD to the sim config without needing SolidWorks or a CAD
    kernel, so the placeholder geometry can be replaced with measurements.
    STL side: volume by the divergence theorem over a closed triangle mesh,
    which is exact, not approximate - validated against a 10x20x30 box
    (6.00 cm3 vs 6000 mm3 truth) and a 720-segment cylinder (5.03 vs
    5026.5 mm3). Volume times material density gives the real MASS_COXA /
    MASS_FEMUR / MASS_TIBIA. Also reports bounding box and centre of mass.
    STEP side: bounding box, plus every CYLINDRICAL_SURFACE with its axis.
    Coaxial faces are collapsed into distinct axes and the perpendicular
    distanc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
2026-09-10 Measure the CAD leg: it is 3x too big for DT996 servos
    The first CAD leg is drawn at 459 mm reach. The servos chosen and
    costed cannot carry it, and the geometry has to settle before anything
    downstream is worth regenerating.
    Measured, not estimated. Joint axes come from fitting cylinders to the
    exported meshes, which share one assembly frame: coxa 59.8, femur
    139.9, tibia 259.0 mm axis to axis, against the 30/60/90 placeholder.
    The axes are the bores in the DRIVEN parts - a naive fit locks onto the
    servo case's own rounded end (r = 10.37 mm, identical across all three
    servo instances), which sits ~7 mm off the true axis.
    Torque follows from tools/scale_torque.py against printed masses rea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
    [Assemblage1 - SERVO-1.STL, Assemblage1 - SERVO-2.STL, Assemblage1 - SERVO-3.STL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]
2026-09-11 Scale the leg to 42 % of the CAD and keep the DT996 servos
    Replaces the placeholder 30/60/90 chain with the measured CAD leg scaled
    to fit the servos already chosen. Links become 25 / 59 / 109 mm, holding
    the CAD's proportions to within a percent - the same leg, smaller, not a
    different design. Stance reach 102 mm, foot span 344 mm, all-up 1.61 kg.
    Torque 0.54 N.m standing and 0.94 N.m climbing against 1.12 usable, a
    1.19x margin.
    Not the 33 % originally asked for, because torque was never what blocked
    it: at 33 % the margin was a comfortable 1.9x, but articulation 1 fell to
    27 mm while still needing to bolt on a 40.7 mm servo. Servos are a fixed
    size, so uniform scaling fails from below lo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
    [hexapod_body.urdf.xacro, hexapod_control.xacro]
2026-09-15 Firmware stage 1: servos, calibration and the gait loop
    ESP32-S3 firmware for the bench: two PCA9685s, an 18-joint calibration
    console and the tripod gait. No WiFi or camera yet - this is everything
    testable with a board, two driver boards and a single servo.
    The kinematics are a port of hexapod_gait/leg_ik.py and gait.py, and a
    port is exactly where a sign flips unnoticed, so they are checked rather
    than trusted: tools/test_firmware.py regenerates fixtures FROM the
    Python, compiles the C++ against them and runs it. 2615 checks, 0
    failures, worst walking excursion 33.7 of 80 deg. It compiles with zig's
    C++ frontend (pip install ziglang) because this machine has no C++
    toolchain and zig need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
    [main.cpp]
2026-09-15 Generate the leg parts from robot_config.py
    Three printed parts - coxa_link, femur_link, tibia - built parametrically
    with build123d and exported as STEP and STL. Axis spacing comes from the
    config, so the parts cannot disagree with the simulator: the hand-drawn
    leg missed it by 2.5x and nobody knew until the export was measured.
    Verified from the exported STLs rather than asserted by the script, using
    the same cylinder fitter that measured the hand-drawn leg: 25.02 / 58.97
    / 109.01 mm against a config of 25 / 59 / 109.
    Two real bugs found while building it, both of which would have produced
    parts that looked fine and could not be assembled:
    The first design tried to straddle each servo w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
    [coxa_link.step, coxa_link.stl, femur_link.step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]
2026-09-15 Generate the whole robot: body, camera mast, stance assembly
    Adds everything the legs bolt to. The body plate carries six coxa servo
    mounts at the hip positions from robot_config, holes for two PCA9685s
    and the ESP32-S3 carrier, battery strap slots and a socket for the mast.
    The mast stands the camera above the robot, tilted 15 deg down.
    The assembly is not decoration: it chains the REAL mechanical offsets -
    wall thicknesses, servo heights, horn faces - and then asks where each
    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
    [assembly.stl, body.step, body.stl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]
2026-09-15 Style the robot as a spider, and give it a face
    Body, head and legs reshaped for character, with the LCD and proximity
    sensor the user plans to fit designed in rather than bolted on after.
    The body is overlapping circular lobes down the centreline instead of a
    rectangle: narrow head, broad thorax across the leg roots, pinched
    waist, bulbous abdomen. Each lobe is sized by what sits under it - the
    abdomen by the LiPo, the thorax by the hip spacing - so the silhouette
    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
    [assembly.stl, body.step, body.stl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]
2026-09-15 Add the abdomen dome and the electrical components
    The abdomen is a domed shell over the rear of the plate, open underneath,
    holding the battery. The head, plate and legs were all flat 5 mm sheet
    until now, which is what kept the robot reading as a bracket assembly
    rather than a creature.
    Two OpenCASCADE boolean traps on the way there, both of which produce a
    part that looks fine until it is measured:
    Clipping both the outer and inner dome at exactly z=0 gives them a
    coincident planar face, and the subtraction returns an EMPTY solid - not
    an error. The inner shell is now left running below zero, which also
    opens the underside, which is what a battery shell wants anyway.
    The first dome fol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
    [abdomen.step, abdomen.stl, assembly.stl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]
2026-09-15 Fix the battery fit: underslung, not in the abdomen
    The pack does not fit inside the dome in any orientation, and a
    component-research pass settled why. A 2S pack is 90 x 34 x 20 mm; the
    dome's cavity is 85 x 75 at plate level, but the ellipsoid tapers to
    70 mm long at the pack's 20 mm top face, so its front and rear top
    corners fall outside the shell however it is turned. Forcing it would
    need ABDOMEN_A ~60 and ABDOMEN_H ~50, putting the dome's front at x=-14
    - through the waist, over the rear driver, and into the 15 mm the rear
    legs need to sweep past. The dome's job is the two UBECs, which use 35
    of its 118 cm3.
    The pack now hangs under the plate at x=-62, where 59 mm of ground
    clearance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
    [abdomen.step, abdomen.stl, assembly.stl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]
2026-09-15 Restyle the CAD as a skeletal machined chassis
    The reference build the styling is aimed at gets its look from three things
    this design did not have: triangular voids between edge rails, a faceted
    plate with a point at each hip, and blade legs rather than slabs.
    Legs. The femur and tibia are now Warren trusses - alternating triangular
    voids inset from two edge rails. This is not only a look: a plate in bending
    carries almost nothing near its neutral axis, and on the tibia it is mass at
    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
    [abdomen.step, assembly.stl, assembly_printed_only.stl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]
2026-09-15 Fix what the component research found, and the checks that missed it
    The component-dimension workflow came back. Most of what it found was not a
    packaging problem but a CHECKING problem: three separate blind spots that let
    real collisions through while the script printed "none".
    Blind spot 1 - a hole is a subtraction, so it carries no screw. The shunt sat
    under four fastener tails with 1.5 mm of air and the expander swallowed three
    of the rear driver's mounting screws; no solid met a solid, so nothing was
    reported. Screws, nuts and proud heads are now solids, built from the same
    _plate_holes() list the plate is drilled from.
    Blind spot 2 - the 60 mm3 sliver threshold was not small enough t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
    [abdomen.step, assembly.stl, assembly_printed_only.stl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]
